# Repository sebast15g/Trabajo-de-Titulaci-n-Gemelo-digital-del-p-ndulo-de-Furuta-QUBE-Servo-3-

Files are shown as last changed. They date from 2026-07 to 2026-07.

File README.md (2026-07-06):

<h1 align="center">Gemelo digital del péndulo invertido de Furuta</h1>
<h3 align="center">Quanser QUBE-Servo 3 · modelo analítico · EKF · control · tiempo real</h3>

<p align="center">
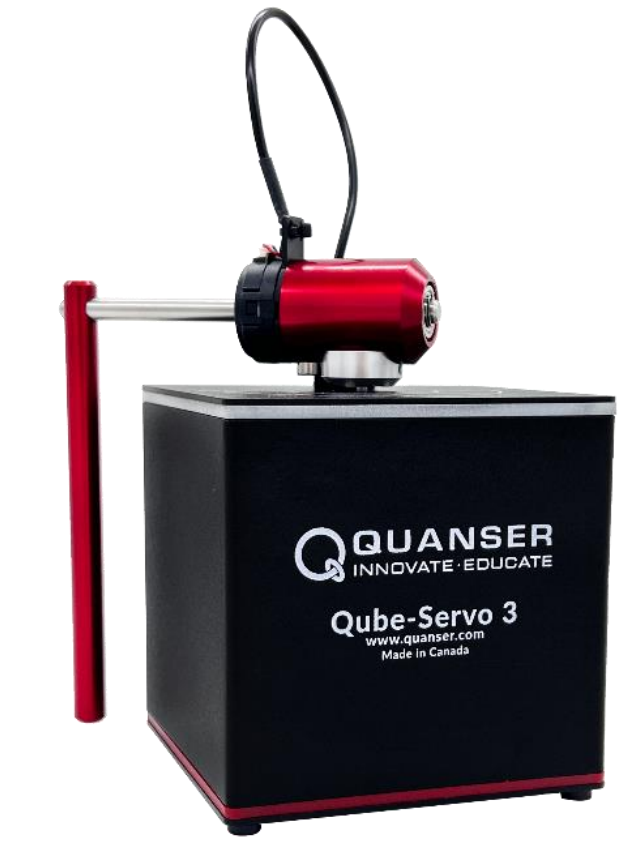
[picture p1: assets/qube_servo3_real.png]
Quanser QUBE-Servo 3 con el péndulo de Furuta
  
  &nbsp;&nbsp;&nbsp;
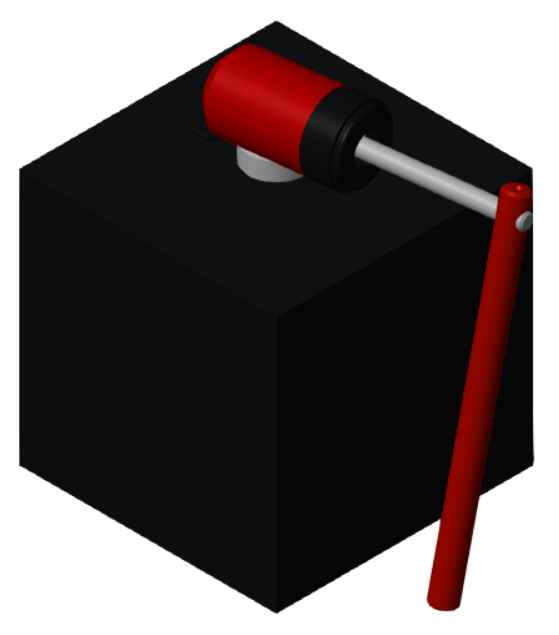
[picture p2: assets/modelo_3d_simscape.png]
Modelo 3D en Simscape Multibody
  
</p>
<p align="center"><em>Izquierda: el equipo real (planta M0). Derecha: el modelo 3D en Simscape Multibody (M2).</em></p>

<p align="center">
  
  
  
  
</p>

---

Este repositorio reúne el código, los datos, los modelos y las figuras del trabajo de
titulación *«Evaluación del impacto de la simulación en tiempo real en la fidelidad de un
gemelo digital aplicado al péndulo invertido QUBE-Servo 3»* (Universidad de Cuenca,
Facultad de Ingeniería, 2026).

El objetivo es construir un **gemelo digital** del péndulo de Furuta del equipo Quanser
QUBE-Servo 3, validarlo contra el equipo real y estudiar cómo influye la **simulación en
tiempo real** en su fidelidad, sincronización y desempeño.

## Idea en una figura

El trabajo maneja tres representaciones de la misma planta y las hace convivir:

| | Descripción |
|---|---|
| **M0 — real** | El equipo físico QUBE-Servo 3 (foto de la izquierda), leído por QUARC. |
| **M2 — 3D** | Modelo de alta fidelidad SolidWorks → Simscape Multibody (imagen de la derecha). |
| **M1 — analítico** | Modelo por Euler-Lagrange, `f(x,u)` y jacobianos en forma cerrada; es el gemelo que se despliega. |

Sobre M1 se cierra el lazo con un **observador (filtro de Kalman extendido, EKF, de estado
aumentado)** que estima el estado y la perturbación del cable a partir de los encoders, y
un **banco de control** (swing-up por energía + balance LQI/LQR/PD/PID). El mismo M1 se
ejecuta sin cambios sobre cuatro sustratos (SIM, QSM, QHW, RTB) para medir el efecto de la
simulación en tiempo real.

## Modelo principal: `DT_bidireccional_RT`

El modelo integrador de todo el trabajo es **`modelos/gemelo/DT_bidireccional_RT.slx`**. Es
el gemelo digital bidireccional: acopla la planta real (por HIL/QUARC) con la planta digital
(Simscape 3D), comparte el observador EKF y el banco de control, y sincroniza ambos lados.

<p align="center">
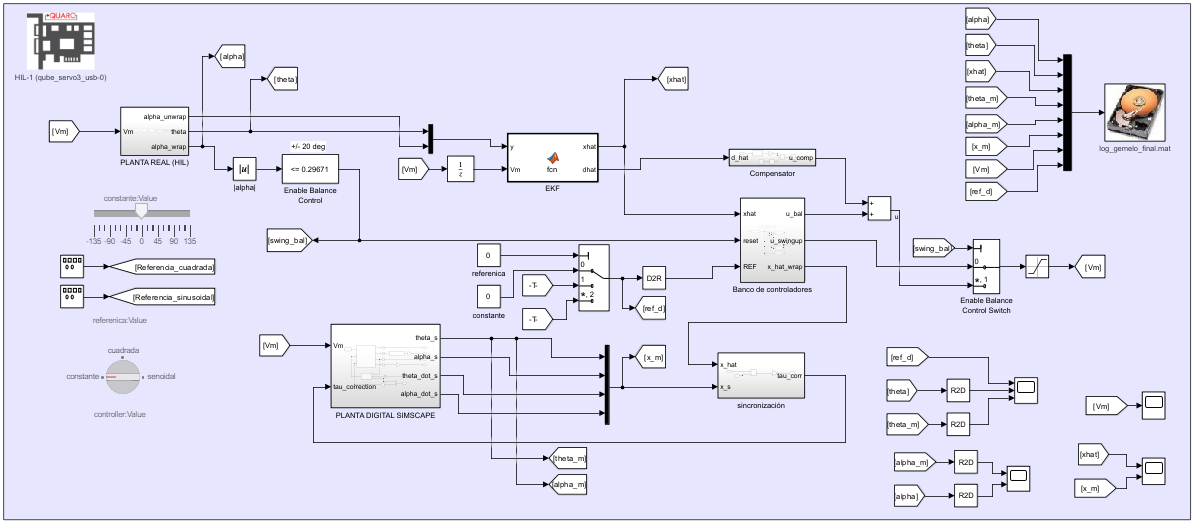
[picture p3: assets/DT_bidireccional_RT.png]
Modelo DT_bidireccional_RT en Simulink/QUARC
  
</p>

De un vistazo, en la captura: el bloque **PLANTA REAL (HIL)** (lectura de θ, α por QUARC), el
**EKF** que entrega `x̂` y la perturbación estimada `d̂`, el **banco de controladores** con la
conmutación swing-up → balance (`|α| ≤ 0.297 rad`), la **PLANTA DIGITAL SIMSCAPE** (el espejo
3D), el bloque de **sincronización** entre ambos, y el registro a `log_gemelo_final.mat`.

> Nota: `DT_bidireccional_RT` compila y corre; los ensayos de seguimiento en tiempo real
> cargan referencias grabadas por corrida (`ref_u`, `ref_xhat`) y la ganancia de sincronía
> `Ksync_tau`, propios de cada experimento.

Otros modelos de interés:

| Modelo | Rol |
|---|---|
| `modelos/gemelo/DT_bidireccional_RT.slx` | **Gemelo bidireccional (principal).** |
| `modelos/gemelo/Comparacion_real_modelo3d.slx` | Real y 3D en paralelo, sin sincronización (verificación de construcción). |
| `modelos/ekf_control/Digital_twin_ekf_E1…E5.slx` | Construcción incremental del EKF + control (etapas E1–E5). |
| `modelos/modelo_3d/Ensamblaje_..._v4.slx`, `Model3d_Furuta_Pendulum.slx` | Modelo 3D (SolidWorks → Simscape), base de la calibración. |
| `RTS_modalidades/` | El mismo M1 en las 4 modalidades de ejecución (SIM/QSM/QHW/RTB). |

## Estructura del repositorio

```
TESIS_FINALES/
├── codigo/            Scripts y funciones de MATLAB, por etapa
│   ├── parametros_furuta.m        Parámetros físicos finales (cargar primero)
│   ├── referencia/                Parámetros de referencia de Quanser
│   ├── identificacion/            Identificación por ensayo aislado 
│   ├── validacion/                Validación de fricción y retorno del cable
│   ├── modelo_control/            Modelo analítico M1, EKF y control 
│   └── gemelo/                    Real vs. 3D y gemelo bidireccional 
├── datos/             Datos de entrada y registros (.mat/.csv), por tema
├── figuras/           Figuras del Desarrollo y del Anexo, por tema
├── modelos/           Modelos de Simulink/Simscape (.slx), por tema
├── RTS_modalidades/   Las 4 modalidades (SIM/QSM/QHW/RTB) y su comparación
├── assets/            Imágenes de esta portada
├── setup_paths.m      Prepara el path y carga los parámetros
├── repo_root.m        Devuelve la raíz del repositorio
├── INDICE_documentacion.md   Índice unificado de la documentación
├── LICENSE            Licencia MIT
└── CITATION.cff       Cómo citar
```

Cada carpeta de nivel superior incluye su propio `README.md` con el detalle de su contenido.

## Requisitos

- MATLAB (probado en R2025a; compatible desde R2019a, versión de la `quarc_library` usada).
- Simulink, Simscape y Simscape Multibody.
- Symbolic Math Toolbox (derivación del modelo y de las funciones del EKF).
- Control System Toolbox (LQR/LQI) y Simulink Control Design (linealización del 3D).
- Statistics and Machine Learning Toolbox (algunos estimadores de la identificación).
- QUARC (Quanser) para las corridas en tiempo real y contra el hardware; no es necesario
  para la simulación offline ni para los scripts de post-proceso.

## Uso rápido

```matlab
% 1) Desde la raíz del repositorio, preparar el path y cargar los parámetros:
setup_paths        % añade codigo/ datos/ modelos/ RTS_modalidades/ al path
                   % y deja el struct 'p' en el workspace (parametros_furuta.m)

% 2) Abrir cualquier modelo desde su subcarpeta: su PreLoadFcn localiza la raíz,
%    arma el path y carga los parámetros automáticamente. Por ejemplo:
open_system('DT_bidireccional_RT')      % el modelo principal
open_system('Digital_twin_ekf_E1')      % una etapa del EKF

% 3) Correr los scripts de identificación / validación / comparación, p. ej.:
calc_friction               % identificación de la fricción del motor
comparar_analitico_simscape % modelo analítico M1 vs. modelo 3D M2
```

Los scripts resuelven sus datos por el path; no usan rutas absolutas. Los scripts de
post-proceso de las modalidades están en `RTS_modalidades/scripts/`.

## Parámetros físicos (valores finales adoptados)

| Grupo | Parámetro | Valor |
|---|---|---|
| Péndulo (α) | masa `mp`, longitud `Lp` | 0.024 kg, 0.12865 m |
| | Coulomb `Tc_alpha` | 6.1×10⁻⁶ N·m |
| Brazo (θ) | inercia `Jr` (eje motor) | 1.38×10⁻⁴ kg·m² |
| | viscoso `Dr` | 3.975×10⁻⁴ N·m·s/rad |
| Cable del encoder | rigidez `kc` | 2.384×10⁻³ N·m/rad |
| Motor DC | `Rm`, `kt = km` | 7.5 Ω, 0.0422 |
| Muestreo | `Ts` | 0.002 s (500 Hz) |
| Gravedad local | `g` | 9.7807 m/s² |

## Resultados principales

- El modelo analítico M1 reproduce al modelo 3D M2 con RMSE θ = 0.64°, α = 0.83°; polo
  inestable en +13.42 rad/s.
- EKF de estado aumentado sobre el equipo real: RMSE θ, α ≈ 0.03°.
- El sustrato de ejecución no cambia la fidelidad (RTB ≈ QSM ≈ SIM, mismo M1, todas dentro
  de la brecha M1↔M0); el delta entre modalidades mide la simulación en tiempo real (jitter,
  overruns, integrador). Detalle en `RTS_modalidades/`.

## Documentación

El punto de entrada único a toda la documentación es
[`INDICE_documentacion.md`](INDICE_documentacion.md). El estado global del trabajo está en
[`ESTADO_FINAL_PROYECTO.md`](ESTADO_FINAL_PROYECTO.md).

## Licencia y cómo citar

Código, datos y modelos se publican bajo licencia **MIT** (ver [`LICENSE`](LICENSE)). Si
utiliza este repositorio, por favor cite la tesis asociada (ver
[`CITATION.cff`](CITATION.cff)):

> Bermeo García, P. A.; Guazhima Fernández, S. S. (2026). *Evaluación del impacto de la
> simulación en tiempo real en la fidelidad de un gemelo digital aplicado al péndulo
> invertido QUBE-Servo 3*. Trabajo de titulación, Universidad de Cuenca, Facultad de
> Ingeniería.

## Autores

**Pablo Andrés Bermeo García** · **Sebastián Stalin Guazhima Fernández**
Universidad de Cuenca — Facultad de Ingeniería

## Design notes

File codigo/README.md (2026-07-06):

# codigo/

Scripts y funciones de MATLAB del gemelo digital, organizados por etapa. Antes de
ejecutar cualquier archivo, correr `setup_paths.m` en la raíz del repositorio: arma
el path y deja el struct de parámetros `p` en el workspace (`parametros_furuta.m`).

- `parametros_furuta.m` — parámetros físicos finales (archivo central; cargar primero).
- `Ensamblaje_..._v4_DataFile.m` — `smiData` (geometría/inercias/CoM del CAD).
- `referencia/` — parámetros de referencia del péndulo rotatorio de Quanser.
- `identificacion/` — identificación de parámetros por ensayo aislado (§4.3):
  `motor_friccion/`, `cable_theta/`, `contacto_topes/`, `alpha/`, `inercia_Jr/`,
  `calibracion_voltaje/`.
- `validacion/` — validación de la fricción del motor y del retorno libre del cable (§4.3).
- `modelo_control/` — modelo analítico M1, observador EKF y banco de control (§4.4–§4.6).
- `gemelo/` — comparación real vs. modelo 3D y demostración del gemelo bidireccional (§4.8).

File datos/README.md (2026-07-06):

# datos/

Datos de entrada y registros (`.mat`/`.csv`) que consumen los scripts, por tema. Se
resuelven por el path (`setup_paths.m`), sin rutas absolutas.

- `motor_friccion/`, `cable_theta/`, `contacto_topes/`, `alpha/`, `calibracion_voltaje/`
  — datos de identificación de parámetros (§4.3).
- `control/` — logs del banco de controladores (LQR/LQI/PD/PID).
- `gemelo/` — logs de sincronización y de verificación de construcción (real vs. 3D).
- `modelo_control/` — artefactos del modelo y del observador (`banco_controladores.mat`,
  `modelo_furuta_EKF.mat`).
- `validacion/` — salidas de simulación para las figuras de validación.

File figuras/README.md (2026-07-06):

# figuras/

Figuras del capítulo de Desarrollo y del Anexo, organizadas por tema: `modelo_3d/`,
`motor_friccion/`, `cable_theta/`, `contacto_topes/`, `alpha/`, `modelo_analitico/`,
`ekf/`, `control/`, `gemelo/`, `validacion/`. Los nombres de archivo coinciden con los
que cita el documento LaTeX de la tesis.

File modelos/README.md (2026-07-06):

# modelos/

Modelos de Simulink/Simscape (`.slx`) por tema: `modelo_3d/`, `motor_friccion/`,
`cable_theta/`, `contacto_topes/`, `alpha/`, `ekf_control/`, `gemelo/`, `validacion/`.

Cada modelo trae un `PreLoadFcn` que localiza la raíz del repositorio (buscador por
marcador), arma el path y carga los parámetros; no requiere preparación manual. Los
modelos 3D ejecutan además el `DataFile` para poblar `smiData` antes de compilar.

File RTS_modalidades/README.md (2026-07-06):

# RTS_modalidades — paquete de la etapa de modalidades (fidelidad + RTS)

Consolida el estudio de las **4 modalidades** del gemelo M1 del péndulo de Furuta contra la planta real
M0, en los 3 experimentos (E1 caída libre, E2 respuesta forzada, E3 lazo cerrado swing-up+balance+EKF).

## Estructura
- **`RTB/`** — RT Box (PLECS): figuras a 2 ms, overlays, barridos, métricas, esquemáticos PLECS, scopes PDF, sweeps CSV.
- **`QSM/`** — QUARC-modelo: esquemáticos, scopes, figuras del barrido (fast timer).
- **`QHW/`** — QUARC-real (M0): esquemáticos, scopes.
- **`SIM/`** — sim normal: métricas RTF.
- **`comparacion/`** — 13 figuras comparativas + `comparacion_4mod.mat`, `barridos_qsm.mat`, memo comparativo.
- **`scripts/`** — todos los `.m` del post-proceso.
- **`docs/`** — documentos por modalidad + maestras + hallazgos + memos.

## Documentos por modalidad (docs/)
- `doc_RTB.md` y `doc_QSM.md` — **extensos** (implementación, solver, hallazgos, RTS, resultados).
- `doc_QHW.md` y `doc_SIM.md` — breves (corridas directas, sin ajustes de por medio).
- `COMPARACION_4_modalidades.md` — tablas de fidelidad y RTS + lectura para la tesis.
- Transversal: `hallazgo_QUARC_timer_floor_RTS.md`, `memo_correccion_2ms_RTBOX.md`,
  `GUIA_ubicacion_resultados_rtbox.md`, maestras RTS y SIM/QUARC.

## Figuras comparativas (comparacion/)
- 4-way (las 4 modalidades): `comp_E1_alpha_4mod`, `comp_E2_alpha_theta_4mod`,
  `comp_E3_{alpha,theta,Vm,alphadot,NIS,E}_4mod`.
- Cada modalidad a solas vs el real (3 subplots): `comp_E1_alpha_vsreal`,
  `comp_E2_{alpha,theta}_vsreal`, `comp_E3_{alpha,theta}_vsreal`.
- Convención: en E3 la α es continua (sin envolver) y referenciada a balance=0; se refleja SOLO la
  modalidad cuyo swing-up viene del lado contrario al real (resultó ser RTB).

## Resultado en una línea
El sustrato **no** cambia la fidelidad: RTB≈QSM≈SIM (misma M1) y todas aproximan al real M0 dentro de la
brecha M1↔M0 (~5% en E1; QSM≈QHW casi exacto en E3). El delta entre modalidades mide la **RTS**: SIM es la
cota libre (RTF 12–35×); RTB es *compute-bound* y determinista (jitter sub-µs, pero corrió a RTF≈2); QSM es
*timer/jitter-bound* (piso 1 ms sin fast timer, jitter ~320 µs); QHW usa el timebase HIL (jitter ~36–70 µs).
La diferencia numérica entre RTB y QSM/SIM con el mismo modelo es el **integrador** (Euler 0.5 ms en la box
vs RK4/ode4 en QUARC).

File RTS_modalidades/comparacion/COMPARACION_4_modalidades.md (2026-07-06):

# Comparación de las 4 modalidades — fidelidad y RTS (E1/E2/E3)

Cierre del estudio: el mismo gemelo M1 ejecutado en cuatro sustratos contra la planta real M0.
Modalidades: **RTB** (RT Box/PLECS), **QSM** (QUARC-modelo), **SIM** (sim normal offline), **QHW**
(QUARC-real = M0). Post-proceso reproducible en `SIM_QUARC_RTS/postproceso_comparaciones/`
(`comparar_4mod.m`, `crosscheck_rtbox.m`, `procesar_barrido_rts.m`). Datos en `comparacion_4mod.mat` y
`barridos_qsm.mat`.

> Convención de figuras: en el swing-up (E3) se homogeneiza el signo de α por modalidad (se invierte si
> el último vaivén antes de la captura viene del lado contrario) para que las curvas calcen. Aplica al
> real o al modelo indistintamente.

## 1. Fidelidad (gemelo vs real M0)

Como RTB, QSM y SIM comparten la MISMA M1, coinciden entre sí; la brecha de fidelidad es M1↔M0 y es
aproximadamente constante entre sustratos (el sustrato no cambia la fidelidad).

**E1 — caída libre (α):**

| modalidad | f_n [Hz] | ζ | ratio f_n vs real |
|---|---|---|---|
| RTB | 1.761 | 0.0525 | 0.97 |
| QSM | 1.724 | 0.0568 | 0.95 |
| SIM | 1.724 | 0.0568 | 0.95 |
| **QHW (M0)** | **1.818** | **0.0390** | — |

RTB/QSM/SIM se agrupan (~1.72–1.76 Hz); el real va ~5 % más rápido (inercias/acoplamiento). RTB queda
levemente por encima de QSM por el integrador (Euler 0.5 ms vs RK4). Figura: `comp_E1_alpha_4mod.png`.

**E2 — respuesta forzada (rangos, misma excitación |Vm|≤1.5 V):**

| modalidad | θ [min,max]° | α [min,max]° |
|---|---|---|
| RTB | [−136.1, 136.0] | [113.4, 237.1] |
| QSM | [−135.8, 135.8] | [123.6, 225.1] |
| SIM | [−135.8, 135.8] | [123.6, 225.1] |
| **QHW (M0)** | [−136.1, 136.2] | [124.1, 234.1] |

θ topa en ±135° en las cuatro; α ~±60° del colgado. RTB oscila un poco más en la cuadrada (0–10 s) por
sensibilidad del tope rígido al integrador, pero acotado al mismo régimen. El seguimiento del brazo (θ) y
de las fases multiseno/chirp es excelente entre las cuatro. Figura: `comp_E2_alpha_theta_4mod.png`.

**E3 — lazo cerrado (swing-up + balance + EKF):**

| modalidad | t_catch [s] | balance % | α̂_std° | θ_std° | NIS |
|---|---|---|---|---|---|
| RTB | 2.72 | 93.8 | 0.51 | 0.66 | 1.10 |
| QSM | 3.13 | 79.1 | 1.11 | 3.10 | 1.50 |
| SIM | 3.13 | 79.1 | 1.11 | 3.10 | 1.50 |
| **QHW (M0)** | 2.65 | 82.3 | 1.12 | 3.14 | 1.52 |

**QSM ≈ QHW casi exacto** (α̂_std 1.11 vs 1.12°, θ_std 3.10 vs 3.14°, NIS 1.50 vs 1.52): el modelo
reproduce el balance real. SIM = QSM (mismo modelo, offline). RTB balancea algo más apretado (α̂_std
0.51°) por sustrato bare-metal. El swing-up es sensible al arranque → t_catch varía (2.65–3.13 s), pero
las cuatro capturan y balancean. Figura: `comp_E3_alpha_4mod.png`. NIS ~1–2 en las cuatro → EKF
consistente.

## 2. RTS (impacto del tiempo real)

El contraste es **libre (SIM) vs tiempo real estricto (QSM/QHW/RTB)** y, dentro del tiempo real, **cómo
topa cada sustrato**.

| modalidad | RTF | TET (punto op., 2 ms) | umbral de overrun | jitter @2 ms | naturaleza |
|---|---|---|---|---|---|
| **SIM** | ≫1 (E1 12.3, E2 35.4, E3 15.4) | n/a | n/a | n/a | libre, sin tiempo real |
| **RTB** | =1 (corrió a ~2× pared, ver nota) | 6.7 µs abierto / 16.8 µs cerrado | ~5 µs abierto / ~10 µs cerrado | sub-µs (hardware-locked) | *compute-bound*, bare-metal |
| **QSM** | =1 hasta ~5 µs (colapsa 1 µs) | ~7–8 µs med (máx 200–415 µs) | ~5 µs (con fast timer) | ~320 µs (software Windows) | *timer/jitter-bound* |
| **QHW (M0)** | =1 | ~8–10 µs med | — (planta física) | ~36–70 µs (timebase HIL) | planta real en tiempo real |

**Barrido de paso (QSM, fast timer):** RTF=1 desde 2 ms hasta 5 µs; colapso en 1 µs (abierto RTF 0.685,
56.7 % overruns; cerrado RTF 0.319, 100 %). TET_max crece de ~200 µs a 36 ms al forzar la tasa (stalls de
Windows). Sin fast timer, QUARC (win64) tiene **piso duro en 1 ms** (rechaza pasos menores: "unable to set
base rate"); el fast timer libera tasas sub-ms a costa de mucho CPU (recomendado en multinúcleo) —
experimental. Tablas en `barridos_qsm.mat`.

**Barrido de paso (RTB):** abierto TET_max ~6.7–7.8 µs, umbral overrun ~5 µs (5120 overruns @5 µs, carga
150 %); cerrado TET_max ~16–17 µs (el EKF ~triplica el TET), umbral ~10 µs (10240 overruns). Fuente
`rts_sweep_*.csv` + Application Log (`rt_E*_<paso>.txt`).

**Notas de RTS:**
- **RTB RTF≈2 (hallazgo aparte):** el modelo avanza 2 ms/muestra y el wall-clock ~1 ms → la box ejecutó a
  2× la velocidad de pared (no sostuvo 1:1). No afecta la fidelidad (dinámica en tiempo-modelo).
- **Contraste de sustratos:** RTB gana en **determinismo** (jitter sub-µs acotado por hardware); QUARC+fast
  timer gana en **throughput mediano** (TET ~µs, CPU potente) a costa de una cola de latencia no acotada
  (stalls de ms) y mucho CPU. El sustrato determinista a paso fino es el **hardware timebase** (RT Box, o
  la tarjeta HIL del QUBE en QHW). Corrección de la tesis: QUARC (win64) usa **timer de software** de
  Windows, no de hardware.

## 3. Lectura para la tesis

- **Fidelidad:** M1 es un gemelo válido, con brecha M1↔M0 de ~5 % en frecuencia (E1), ~±10° cerca del tope
  (E2, cable-jack/conector) y balance real ligeramente más disperso (E3, stiction/ruido). La brecha es del
  MODELO, no del sustrato: RTB≈QSM≈SIM. El lazo cerrado (E3) es la validación más relevante y QSM≈QHW.
- **RTS:** el delta entre modalidades mide el impacto del tiempo real. SIM es la cota libre; RTB y QHW son
  deterministas por hardware; QSM depende del timer de software (piso 1 ms sin fast timer, jitter alto).
- **Pendiente de redacción:** RMSE θ/α alineado por τ* (E2, misma excitación) para cuantificar la brecha
  punto-a-punto; y la sección de Desarrollo "Implementación de las modalidades" (4 modalidades, E1/E2/E3,
  montajes con las capturas `*_SIMULINK.png`/`*_PLECS.png` y scopes `*_scope_*`).

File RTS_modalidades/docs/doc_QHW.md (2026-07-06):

# Modalidad QHW — QUARC-real (planta física, = M0) · recopilación

Modalidad de **la planta real bajo control en tiempo real**: el QUBE-Servo 3 físico conectado al kernel
QUARC por la **HIL API** de Quanser (`HIL Initialize`, `HIL Read Encoder`, `HIL Write Analog`). Es la
**referencia M0** contra la que se mide la fidelidad de las otras tres. Corridas simples, sin barrido ni
ajustes especiales: la planta física siempre corre en tiempo real. Datos en
`SIM_QUARC_RTS/{E1_QHW,E2_QHW,E3_QHW}`.

## 1. Montaje

Mismo esquema de Simulink/QUARC que QSM, pero la planta simulada se reemplaza por el I/O físico (HIL): el
encoder entrega θ y α, y el analógico escribe Vm al motor. Esquemáticos en `E*_QHW_SIMULINK.png`; scopes
de ángulos en `E*_scope_*.png` / `*_scope_theta_alpha.png`. En E3 el retardo del lazo lo introduce el
propio I/O físico (no hace falta el `Unit Delay z⁻¹` de QSM/SIM). **Signo del actuador: aquí SÍ va el `−1`
de `For +ve CCW`** (convención del hardware Quanser).

## 2. Consideraciones (pocas, por ser corridas directas)

- **E1 (caída libre):** el péndulo se **levanta a mano** hasta cerca del invertido y se suelta; el log trae
  un preámbulo de sujeción que hay que **recortar** (desde la soltada) antes de estimar `f_n`/ζ. Lo hace
  `ver_E1_qhw.m` / los overlays (detección del fin del "hold" y del primer cruce del colgado).
- **Convención de α:** el encoder da α con reposo (colgado) ≈ 180°; la comparación con el modelo usa
  `α_real ↔ π − α_modelo` cuando aplica (verificado: en E1 la convención salió **directa**, sin inversión).
- **No hay estado "verdadero"** aparte del encoder: `theta/alpha` = `theta_meas/alpha_meas`; las velocidades
  se toman del EKF o se derivan en post.

## 3. RTS

- **RTF = 1** por construcción (planta física en tiempo real). No hay barrido de paso (la planta no se
  puede acelerar/ralentizar).
- **TET** medio ~8–10 µs (bloque `Computation Time`). **Jitter ~36–70 µs**: la **tarjeta HIL del QUBE
  aporta un *hardware timebase*** que disciplina el muestreo del lazo — por eso QHW tiene mucho menos
  jitter que QSM (~320 µs, solo timer de software), aunque compartan el mismo kernel QUARC. Coincide con la
  recomendación de Quanser de usar un hardware timebase para Ts ≤ 2 ms.

## 4. Resultados (referencia de fidelidad M0)

- **E1:** f_n=1.818 Hz, ζ=0.0390.
- **E2:** θ ∈ [−136, 136]°, α ∈ [124.1, 234.1]°.
- **E3:** captura 2.65 s, balance 82.3%, α̂_std 1.12°, θ_std 3.14°, NIS 1.52. El balance real es
  reproducido casi exactamente por QSM.

## 5. Layout y scripts

QHW E1/E2 (6 filas): `[t, seq, t_model, θ, α, Vm]`. QHW E3 (14 filas): `[t, seq, θm, αm, Vm, θ̂, α̂, θ̇̂,
α̇̂, d̂, nis, mode, E, θref]` — **`mode` es la fila 12** (binaria) y la fila 13 es E (mJ); decodificado por
estadísticas para no confundir canales. Carga con `cargar_log_quarc.m`; verificación con `ver_E1_qhw.m` y
los overlays `overlay_qhw_rtb.m`.

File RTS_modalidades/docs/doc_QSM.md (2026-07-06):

# Modalidad QSM — QUARC-modelo (planta analítica M1 en el kernel de tiempo real) · recopilación completa

Modalidad de **simulación en tiempo real del gemelo M1 en el kernel QUARC** (target `quarc_win64`, sobre
Windows), sin hardware en el lazo. Junto con RTB, la más extensa por el trabajo de RTS y los hallazgos del
timer. Recopila montaje, solver, hallazgos del piso de 1 ms y el fast timer, barrido y resultados. Datos
en `SIM_QUARC_RTS/{E1_QSM,E2_QSM,E3_QSM}`; scripts/figuras en `TESIS_FINALES/RTS_modalidades/`.

## 1. Qué es y cómo se montó

El mismo M1 corre como bloques de Simulink compilados al kernel de tiempo real de QUARC en el PC. La
planta es **`furuta_planta_analitica.m`** (MATLAB Function): transcripción literal del C-Script `PLANTA`
de la RT Box (dinámica 2-DOF + tope θ=±135° + encoder), **verificada contra `furuta_f_aug` a 1.14e-13**.
El EKF es `ekf_step.m` (un paso del EKF aumentado, `nis` como reducción escalar para codegen). Swing-up de
Quanser + balance LQI. Esquemáticos en `E*_QSM_SIMULINK.png`; scopes de ángulos en `*_scope_*.png`.
Ruptura del lazo en E3 con `Unit Delay z⁻¹` (2 ms) para romper el lazo algebraico de la MATLAB Function
(feedthrough). Signo del actuador SIN el `−1` de `For +ve CCW` (ese `−1` es solo del hardware real, QHW).

## 2. Solver (clave de por qué difiere de la RT Box)

QSM/SIM integran M1 con **RK4 (`nsub=4` → subpaso 0.5 ms) = ode4**, dentro de la MATLAB Function; el
solver de Simulink/QUARC es **fixed-step ode4 (o discreto) a 2 ms**. La RT Box, en cambio, integra las
mismas ecuaciones con **Euler explícito** (su target no ofrece ode4 para el C-Script continuo). Misma
física y parámetros, distinto integrador → RK4 (QSM) es más preciso que Euler (RTB); la diferencia es
pequeña en E1 (1.72 vs 1.76 Hz) y visible bajo golpes al tope en E2. Es la razón numérica de que dos
modalidades con "el mismo modelo" no den bit-idénticas.

## 3. Hallazgo principal — piso de tasa base de 1 ms (win64) y fast system timer

Documentado en `hallazgo_QUARC_timer_floor_RTS.md`. Resumen:
- Por defecto, `quarc_win64` usa el **timer de software de Windows con resolución de 1 ms**. Solo admite
  pasos base múltiplos de 1 ms. **Por debajo de 1 ms el kernel rechaza el base rate** ("Unable to set base
  rate. A value is outside the valid range" / "Actual period will be 0"), tanto en Monitor & Tune como en
  standalone (descarta que sea límite de External Mode). Es un **límite entre QUARC y Windows**, no del
  cómputo (el TET sobra: ~7–8 µs). Quanser mismo llama "crude and inaccurate" a la tasa de 1 kHz de
  Windows.
- **Corrección importante de la tesis:** QUARC (win64) usa **timer de software**, NO "timer de hardware".
- **Checklist para ir más allá de 1 ms (experimental):** activar **"Allow use of fast system timer"**
  (Configuration Parameters → Code Generation → QUARC). Esto libera pasos sub-ms usando más recursos de los
  **núcleos de CPU** (muy intensivo en CPU; recomendado en sistemas con >2 núcleos; **siempre deshabilitado
  en 1 CPU**). Sin él, la corrida a <1 ms **da error de ejecución** (el piso descrito). Con él activado, el
  kernel acepta hasta 1 µs. Correr en **standalone** (`quarc_run` o doble-clic al `.rt-win64`), NO en
  Monitor & Tune (External Mode topa a 1 kHz por `quarc_comm`).
- **Caveat de logging a tasas rápidas:** el `seq` de 16 bits se desborda (a 1 µs, 15 M muestras) y corrompe
  el `t_model` reconstruido; usar el `t` del target y el `t_wall`, o loguear `seq` a 32 bits.

## 4. Captura de RTS y barrido de paso

Bloques QUARC: **`Computation Time`** (TET, opción *Output computation time of task*), **`System Time`**
(wall clock), **`Counter Free-Running`** (`seq`), dos `To File` (fid y rt=`[t,seq,t_model,t_wall,TET]`).
Post-proceso del barrido con **`procesar_barrido_rts.m`** (RTF, TET min/med/máx, overruns=#TET>paso, paso
real). El barrido es exclusivo de QSM (planta simulada): en QHW la planta es física y siempre corre en
tiempo real; en SIM no hay tiempo real.

**Barrido con fast timer (E1 abierto / E3 cerrado):**

| paso base | RTF abierto | RTF cerrado | TET med | TET máx | overruns |
|---|---|---|---|---|---|
| 2 ms → 500 µs | 1.000 | 1.000 | 7–10 µs | 200–600 µs | 0 |
| 100 µs | 1.000 | 1.000 | 4–5 µs | ~500 µs | 0.1 % |
| 10 µs | 1.000 | 1.000 | 2–3 µs | 0.8–2.6 ms | 1–2 % |
| 5 µs | 1.000 | 1.000 | 1.6–3 µs | 1.6–3.1 ms | 5–7 % |
| **1 µs** | **0.685** | **0.319** | ~1–2 µs | **13–36 ms** | 57–100 % |

Lectura: QSM **mantiene RTF=1 hasta ~5 µs** (con fast timer) y colapsa en 1 µs; alcanza esencialmente el
mismo paso fino que la RT Box (~5–10 µs), pero el **peor caso** (TET_max) crece a decenas de ms por los
stalls de scheduling de Windows, frente al jitter sub-µs de la box. Es *timer/jitter-bound* (con fast
timer) vs *compute-bound* (RT Box). Tablas en `barridos_qsm.mat`. Figuras
`E1_qsm_barrido_fasttimer.png`, `E3_qsm_barrido_abierto_vs_cerrado.png`.

**Jitter en el punto de operación (2 ms):** ~320 µs (solo timer de software de Windows, sin hardware
timebase) — mucho mayor que QHW (~36–70 µs, timebase HIL) y que la box (sub-µs). Para el punto de
operación conviene **desactivar el fast timer** (baja el TET_max y da el jitter representativo del sustrato
estándar).

## 5. Resultados

- **E1:** f_n=1.724 Hz, ζ=0.0568.
- **E2:** θ ±136°, α ∈ [123.6, 225.1]°.
- **E3:** captura 3.13 s, balance 79.1%, α̂_std 1.11°, θ_std 3.10°, NIS 1.50 → **≈ QHW casi exacto** (el
  modelo reproduce el balance real).

## 6. Scripts y archivos

`cargar_log_quarc.m` (carga robusta a MAT v4 mal finalizado), `procesar_barrido_rts.m`, `run_sim_normal.m`
(comparte con SIM), `furuta_planta_analitica.m`, `ekf_step.m`, `setup_swingup.m`. Doc del hallazgo:
`hallazgo_QUARC_timer_floor_RTS.md`. Maestra: `DOCUMENTACION_MAESTRA_SIM_QUARC_E1E2E3.md`.

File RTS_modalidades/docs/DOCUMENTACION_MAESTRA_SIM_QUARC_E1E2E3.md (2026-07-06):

# Documentación maestra — modalidades Simulink / MATLAB / QUARC (E1/E2/E3) y estudio de RTS

Documento de recopilación y procedimiento de la fase **Simulink/MATLAB/QUARC** del estudio de
fidelidad del gemelo digital del péndulo de Furuta (QUBE-Servo 3) y del impacto de la simulación
en tiempo real (RTS). Es la contraparte de `DOCUMENTACION_MAESTRA_RTS_E1E2E3.md` (RT Box) y cierra
las **tres modalidades que faltaban** para completar el estudio de cuatro sustratos. Redactado para
retomar el trabajo sin perder contexto y para alimentar los capítulos de Desarrollo y Resultados.

Estado: **completo** para E1, E2 y E3 en las tres modalidades (fidelidad + RTS + barridos donde
aplica). Falta solo el post-proceso comparativo final (fidelidad cruzada contra M0 + tablas
consolidadas), que es ya redacción de Resultados.

---

## 1. Objetivo y las tres modalidades de esta fase

El estudio compara **el mismo gemelo digital** ejecutado en cuatro sustratos contra la planta real
(M0). La RT Box quedó documentada aparte; esta fase añade las tres modalidades sobre Simulink/QUARC:

| ID | Nombre | Sustrato | Planta | RTF | Naturaleza |
|---|---|---|---|---|---|
| **SIM** | Sim normal | Simulink offline (PC) | modelo M1 (MATLAB Function) | ≫ 1 | libre, sin tiempo real |
| **QSM** | QUARC-modelo | kernel de tiempo real QUARC (PC) | modelo M1 | = 1 | tiempo real, planta simulada |
| **QHW** | QUARC-real | kernel QUARC (PC) + QUBE-Servo 3 físico | planta física M0 | = 1 | tiempo real, hardware (interfaz HIL) |

`RTB` (RT Box, PLECS Coder) es la cuarta modalidad. **M1** = modelo analítico de 4 estados
(`furuta_f_aug`, transcrito a `furuta_planta_analitica.m`); **M2** = modelo 3D Simscape, usado en su
momento para calibrar M1 (no interviene aquí como planta).

Dos familias de métricas, idénticas a la RT Box:
- **Fidelidad** (gemelo vs real): RMSE θ/α, error máximo, `f_n`/`ζ` (E1), índices de desempeño (E3),
  consistencia del EKF (NIS). Salen de las señales del modelo.
- **RTS** (impacto del tiempo real): RTF, TET, overruns, jitter, muestras perdidas. Salen del
  sustrato de ejecución.

**Aclaración de terminología (importante para la redacción).** En la taxonomía X-in-the-Loop, QSM y
RTB son **simulaciones en tiempo real** del gemelo (no HIL: no hay hardware en el lazo); QHW es la
**planta física bajo control en tiempo real** (M0). El término "HIL" se usa solo en el sentido
comercial de Quanser (la interfaz con el QUBE usa la HIL API: `HIL Initialize`, `HIL Read Encoder`,
`HIL Write Analog`), no en el de emulación de planta.

---

## 2. Convenciones comunes (no negociables — comunes con la RT Box §2)

1. **`Ts = 2 ms` (500 Hz)** como malla de muestreo/comparación en las cuatro modalidades.
2. **Solver Simulink/QUARC**: `ode4` (o discreto) a paso fijo `2e-3`. La planta M1 integra internamente
   por RK4 con `nsub = 4` subpasos (`h = 5e-4`, = paso base de la RT Box).
3. **Convención de ángulos**: θ y α en la del control, **α = 0 arriba, α = π colgado**. El encoder
   real entrega α; la comparación con el modelo usa `α_real ↔ π − α_modelo` en post-proceso.
4. **α SIEMPRE unwrapped hacia el EKF/control.** El encoder del QUBE es incremental (cuenta continua);
   la planta M1 entrega `alpha_meas` **cuantizada pero SIN envolver**, para que `nu = y − ŷ` del EKF no
   tenga saltos de 2π durante el swing-up. (En el log de fidelidad puede guardarse envuelta si se
   prefiere; el control usa la unwrapped.)
5. **Excitación E2** = `excitacion_Vm_e2` (33 s, 16500 muestras a 2 ms, |Vm| ≤ 1.5 V), desde
   `From Workspace` con *Interpolate data = OFF (ZOH)*, *Hold final value* — idéntica a la de la box.
6. **Condición inicial**: E1 `AL0 = 0.05` (cae desde arriba), E2 `AL0 = π`, E3 `AL0 = π` (colgado).
7. **El tiempo va como canal explícito** (fila 1 del log). En QUARC el `To File` antepone su tiempo
   automáticamente (a diferencia de PLECS); se reconstruye igual y `cargar_log_quarc.m` lo lee directo.
8. **Signo del actuador**: en SIM/QSM se usa `u = −Ka·[x̂;xᵢ]` sin el `−1` de `For +ve CCW`; ese `−1`
   solo aparece en QHW (hardware Quanser real).

---

## 3. La planta y el controlador (bloques Simulink reutilizados)

- **Planta M1 — `furuta_planta_analitica.m`** (bloque MATLAB Function): integrador discreto
  autocontenido (RK4, `nsub=4`) que es la **transcripción literal del C-Script `PLANTA` de la RT Box**.
  Incluye la dinámica Lagrangiana 2-DOF, el **tope mecánico θ = ±135°** (penalización unilateral
  resorte-amortiguador) y la **emulación del encoder** (cuantización 2π/2048, α unwrapped). Salidas:
  `theta, alpha, dtheta, dalpha, theta_meas, alpha_meas`. **Verificada contra `furuta_f_aug.m` a
  1.14e-13** (params actuales, `g = 9.7807`). No usa `furuta_f_param.m`, que quedó con `g = 9.77`
  horneada (desactualizada; regenerable con `derivar_furuta_f_param.m`).
- **EKF — `ekf_step.m`** (bloque MATLAB Function): un paso del EKF de estado aumentado (5 estados,
  predicción con Jacobiano + corrección + NIS). Entradas `y = [theta_meas; alpha_meas]` (unwrapped),
  `Vm`. Salidas `xhat = [θ̂,α̂,θ̇̂,α̇̂]`, `dhat`, `nis`. `nis` se calcula como reducción escalar
  `sum(nu.*(Sk\nu))` (garantiza `1×1` para codegen). Requiere `furuta_f_aug/_Fc/_meas/_Hjac` en el path.
- **Swing-up + balance**: swing-up de energía de Quanser (`ke=50`, `Er=2·mp·g·lp≈30.2 mJ`, `u_max=6`)
  con conmutación a balance (`catch` ~17–20°). Balance = **LQI del proyecto**
  `K_LQI = [-3.7921 -33.888 -1.4796 -2.9148 -4.4721]` (4 estados + integrador), NO la ganancia por
  defecto de Quanser. Energía `E = 0.5·Jp_cm·α̇² + mp·g·lp·(1+cos α)`, con α̂/α̇̂ del EKF.
- **Ruptura del lazo**: en E3 el lazo `planta → EKF → control → Vm → planta` se cierra con un
  **`Unit Delay z⁻¹`** (2 ms, inicial 0) entre el `Vm` del control y el `Vm` de la planta. En QSM/SIM es
  imprescindible (la planta MATLAB Function es feedthrough → sin el delay hay lazo algebraico). En QHW
  no hace falta: el hardware (HIL Read/Write) introduce el retardo de forma natural.

---

## 4. Logging (mismo vector de fidelidad que la RT Box §5)

Dos `.mat` por corrida unidos por `seq`, con el **tiempo como canal explícito** (fila 1).

- **Fidelidad `fid_E*_<mod>.mat`**:
  - E1/E2 (lazo abierto): `[t, seq, theta, alpha, dtheta, dalpha, theta_meas, alpha_meas, Vm]` (9 filas).
  - E3 (lazo cerrado): `+ [theta_hat, alpha_hat, dtheta_hat, dalpha_hat, dhat, nis, mode, E]`
    (y `theta_ref`) — hasta 18 filas.
  - En **QHW no hay estado "verdadero"** aparte del encoder: `theta/alpha` = `theta_meas/alpha_meas`;
    las velocidades se derivan en post o se toman del EKF.
- **Tiempo real `rt_E*_<mod>.mat`**:
  - **SIM**: solo `RTF` (struct escueto; TET/overruns/jitter = n/a).
  - **QSM/QHW**: `[t, seq, t_model, t_wall, TET]`, con `t_wall` del bloque QUARC **System Time** y `TET`
    del bloque **Computation Time** (opción *Output computation time of task*, modo *Wall clock*).

**Bloques de captura de RTS (QUARC):** `Counter Free-Running` (seq, sample time 0.002),
`System Time` (t_wall, *Wall clock*), `Computation Time` (TET, *Output computation time of task*),
dos `To File` (fid y rt). En SIM esos bloques QUARC son n/a; se desconectan y el RTF sale de
`tic/toc` alrededor de `sim()` (`run_sim_normal.m`).

---

## 5. Hallazgo principal de RTS — piso de tasa base de QUARC (win64)

Documentado en detalle en `hallazgo_QUARC_timer_floor_RTS.md` (en `E1_QSM/`). Resumen:

- Por defecto, el target `quarc_win64` usa el **timer de Windows con resolución de 1 ms**: solo admite
  pasos base múltiplos de 1 ms. **Por debajo de 1 ms el kernel rechaza el base rate** ("Unable to set
  base rate. A value is outside the valid range" / "Actual period will be 0"), tanto en External Mode
  como en standalone. Quanser mismo califica la tasa de 1 kHz de Windows de "crude and inaccurate" [1].
- La casilla **"Allow use of fast system timer"** (Config Params → QUARC) elimina ese piso y permite
  pasos sub-ms, a costa de mucho CPU (recomendado en multinúcleo) [1].
- **Distinción clave (timer-bound vs compute-bound):** la RT Box es *compute-bound* (timer de hardware
  fino; overrunea cuando el TET supera al paso, ~5–10 µs abierto, ~16–17 µs cerrado). QUARC por defecto
  es *timer-bound* (el cómputo sobra —TET ~7–8 µs— pero el reloj del SO topa en 1 ms). Con fast timer,
  QUARC pasa a *compute/jitter-bound* y mantiene RTF=1 hasta ~5 µs (E1 y E3), colapsando en 1 µs
  (RTF 0.68 abierto, 0.32 cerrado; TET_max hasta 36 ms por stalls de Windows).
- **Trade-off del sustrato:** QUARC (PC potente + fast timer) gana en **throughput mediano** (TET ~µs,
  menor que la box); la RT Box gana en **determinismo** (jitter sub-µs acotado por hardware vs stalls de
  ms de Windows). En QUARC el costo del EKF (lazo cerrado) es despreciable porque el PC es rápido; en la
  box es visible (por eso su umbral cerrado 16 µs ≫ abierto 5–10 µs).
- **Jitter según timebase** (a 2 ms, sin overruns): RT Box sub-µs ≪ QHW ~36–70 µs (timebase HW de la
  tarjeta HIL disciplina el lazo) ≪ QSM ~320 µs (solo timer de software Windows, sin hardware timebase).

Referencia: [1] Quanser Inc., "Configuration Parameters," QUARC Documentation,
https://docs.quanser.com/quarc/documentation/configuration_parameters.html

---

## 6. Metodología del barrido de paso (solo QSM)

El barrido de paso base (headroom de tiempo real) es **exclusivo de QSM** (planta simulada): en QHW la
planta es física y corre en tiempo real pase lo que pase; en SIM no hay tiempo real. Procedimiento:

1. Todos los bloques con sample time a **`-1` (inherit)**; controlar la tasa solo con el *Fixed-step
   size = `Ts_base`* del solver → modelo mono-tasa (evita el error "Data integrity issue" de multi-tasa).
2. Barrer `Ts_base`: por defecto solo 2e-3 y 1e-3 (piso del timer); **con fast timer** 5e-4, 2.5e-4, 1e-4,
   5e-5, 1e-5, 5e-6, 1e-6 hasta el colapso de RTF.
3. Correr en **standalone** (`quarc_run` o doble-clic al `.rt-win64`), no en Monitor & Tune (External
   Mode topa a 1 kHz por `quarc_comm`, aparte del kernel). Leer el `rt_*.mat` (Computation Time) o la
   consola de QUARC.
4. Un barrido por **tipo de lazo**: abierto (E1, cubre E2) y cerrado (E3). Post-proceso con
   `procesar_barrido_rts.m` (RTF, TET min/med/max, overruns, paso real vs paso nominal).
5. Fidelidad se toma aparte, en el punto de operación (2 ms).

Caveat de logging a tasas rápidas: el contador `seq` de 16 bits se desborda (a 1 µs, 15 M muestras) y
corrompe el `t_model` reconstruido; usar el `t` del target (fila 1) y el `t_wall`, o loguear `seq` a 32
bits. Para las corridas de punto de operación (2 ms), **desactivar el fast timer** (baja el TET_max y da
el jitter representativo del sustrato normal).

---

## 7. Resultados preliminares (RTS)

**Sim normal (offline, RTF ≫ 1):** E1 RTF 12.3, E2 RTF 35.4, E3 RTF 15.4 (tiempo de pared ~1 s en los
tres; el RTF incluye el overhead fijo de init de Simulink → es un límite inferior conservador). TET/
overruns/jitter = n/a.

**QSM — punto de operación (2 ms):** RTF=1, 0 overruns, 0 muestras perdidas. TET medio ~8–10 µs (abierto)
y ~15 µs (cerrado, con EKF); jitter ~320 µs (software puro, sin hardware timebase).

**QSM — barrido de paso (fast timer):** RTF=1 hasta ~5 µs; colapso en 1 µs. Ver
`E1_qsm_barrido_fasttimer.png` (abierto) y `E3_qsm_barrido_abierto_vs_cerrado.png` (comparativa).

**QHW — punto de operación (2 ms):** RTF=1, 0 overruns, jitter ~36–70 µs (timebase HW de la tarjeta HIL).
Es la referencia M0.

---

## 8. Consideraciones de fidelidad — por qué difieren real (M0) y modelo (M1)

(Se ahondará en la redacción; aquí el resumen de las causas físicas identificadas.)

- **Frecuencia de α (E1, caída libre):** el modelo va ~8–9 % más lento que el real (2.20 vs 2.40 Hz). Es
  dominado por las **inercias** (Jr del brazo, Jp del péndulo) y el acoplamiento con el brazo libre; el
  cable contribuye de forma secundaria. Los parámetros son de CAD (SolidWorks + calibrador), físicamente
  fundamentados; **no se sobreajustan** para no degradar el modelo en el resto del régimen.
- **Cable-jack (E2, cerca del tope):** el conector del encoder se enrosca a la base del QUBE; al girar el
  brazo al tope (±135°) el jack rota y el cable se enrolla, con rigidez dependiente de la posición,
  histéresis y reposo θ₀ que se desplaza. El error de θ crece hacia el tope (14°→18°) y deja un offset
  residual (~14°) que se acumula. **No representable con parámetros constantes** — M1 modela el cable
  como resorte lineal + viscoso. Es una limitación del régimen, no un mis-tuning.
- **Conector USB-C (E2):** el conector físico de alimentación/USB-C obstruye al péndulo cuando |Vm|≥1 V
  lo lanza al tope; le quita amplitud y cambia el rebote. Es un **artefacto del banco de pruebas**, no un
  déficit del modelo — argumento en contra de tocar parámetros.
- **Stiction y ruido (E3, balance):** el real oscila **4× más en θ** que el modelo (std 2.75° vs 0.69°),
  porque el gemelo limpio no tiene cable-jack, stiction, ruido de encoder ni jitter que rechazar. La
  subactuación obliga a mover θ para sostener α; a más perturbación real, más movimiento de θ. Es una
  medida directa de la brecha de fidelidad en lazo cerrado, no un fallo del control.

Conclusión metodológica: M1 es un **gemelo válido para su propósito** (estimación + control + estudio de
RTS), con un **régimen de validez documentado** (excelente a baja frecuencia/amplitud moderada; se
degrada cerca del tope, en alta frecuencia y con el conector). El lazo cerrado (E3) coincide muy bien
real vs modelo (mismo control, tiempos y amplitudes de swing-up), que es la validación más relevante para
un gemelo destinado a control. Como M1 es idéntico en las cuatro modalidades, esta brecha **se cancela**
en el delta entre modalidades → no afecta al estudio de RTS.

---

## 9. Inventario de la carpeta `SIM_QUARC_RTS/`

Estructura por modalidad (paralela a `RTS_SIM_RTBOX1/`). Cada subcarpeta trae el `.slx` del modelo, el
`.rt-win64` compilado (QUARC), los `.mat` de fidelidad y RT, capturas del modelo Simulink y de los
scopes θ/α, y algún `.txt` de consola (se conservan a modo de evidencia; se descartan para el análisis,
que sale de los `.mat`).

- **`E1E2E3_sim_normal/`**: `E1_SIM.slx`, `E2_SIM.slx`, `E3_SIM.slx`; `fid_E{1,2,3}_sim.mat`,
  `rt_E{1,2,3}_sim.mat` (solo RTF); `run_sim_normal.m` (corre offline y mide RTF por `tic/toc`).
- **`E1_QSM/`**: `E1_QSM.slx` + `.rt-win64`; `fid_E1_qsm.mat`; `rt_E1_qsm.mat` (2 ms) y el **barrido**
  `rt_E1_qsm_{2e_3,1e_3,5e_4,1e_4,5e_5,1e_5,5e_6,1e_6}.mat`; capturas `E1_QSM_SIMULINK.png`,
  `E1_qsm_scope_theta_alpha.png`; `.txt` de consola; y **`hallazgo_QUARC_timer_floor_RTS.md`**.
- **`E2_QSM/`**: `E2_QSM.slx` + `.rt-win64`; `fid_E2_qsm.mat`, `rt_E2_qsm.mat` (2 ms); capturas.
- **`E3_QSM/`**: `E3_QSM.slx` + `.rt-win64`; `fid_E3_qsm.mat`; barrido cerrado
  `rt_E3_qsm_{2e_3…1e_6}.mat`; capturas.
- **`E1_QHW/`, `E2_QHW/`, `E3_HQW/`** (planta real, M0): `.slx` + `.rt-win64`; `fid_E*_qhw.mat`,
  `rt_E*_qhw.mat` (solo punto de operación 2 ms, sin barrido — planta física); capturas del modelo y de
  los scopes; `.txt` de consola.
- **`postproceso_comparaciones/`**: `ver_E1_qhw.m` (verificador E1: layout, signo de α, `f_n`/`ζ`,
  jitter/RTF/TET), `E1_overlay_preview.m`, `E2_overlay_preview.m` (overlays real vs analítico con
  detección de inversión de signo), `procesar_barrido_rts.m` (tabla RTS del barrido).

Nombres: `fid_*` = fidelidad, `rt_*` = tiempo real; el sufijo en `rt_E*_qsm_<paso>` = paso base del
barrido. `*_SIMULINK.png` = bloques y conexiones del modelo; `*_scope_*` = scopes θ/α.

> Nota: la subcarpeta de la planta real de E3 está nombrada `E3_HQW` (typo de `E3_QHW`); el contenido es
> el correcto de QHW-E3.

---

## 10. Post-proceso y estado / checklist

- **Carga**: `cargar_log_quarc.m` lee cualquier `.mat` de SIM/QSM/QHW (orienta a señales×N, recorta
  padding, espera el tiempo en la fila 1). `cargar_log_rtbox.m` para la box.
- **Fidelidad**: alinear por correlación cruzada `τ*`, aplicar `α_real ↔ π−α_modelo`, decimar a 2 ms, y
  emitir RMSE θ/α, e_max, `f_n`/`ζ` (E1), índices E3, NIS. `validar_resultados.m` cubre estimación/balance.
- **RTS**: RTF (SIM ≫1; resto =1), jitter/TET/overruns (QUARC, box), barridos (`procesar_barrido_rts.m`).

Checklist:
- [x] SIM — E1/E2/E3 offline + RTF.
- [x] QSM — E1/E2/E3 fidelidad a 2 ms + barridos abierto (E1) y cerrado (E3) + hallazgo del timer floor.
- [x] QHW — E1/E2/E3 fidelidad a 2 ms (M0) + RTS.
- [ ] Post-proceso comparativo final (fidelidad cruzada vs M0 + tablas RTS de las 4 modalidades).
- [ ] Redacción de Desarrollo (esta carpeta, capturas de modelos y scopes) y Resultados (tablas).

---

## Referencia
[1] Quanser Inc., "Configuration Parameters," QUARC Documentation.
    https://docs.quanser.com/quarc/documentation/configuration_parameters.html
    (parámetros *Allow use of fast system timer* y *Stop the model if an overrun occurs*).

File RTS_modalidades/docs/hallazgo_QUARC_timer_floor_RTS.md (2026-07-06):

# Hallazgo — piso de tasa base de QUARC (win64) en el estudio de RTS

Nota técnica para la redacción del capítulo de RTS. Documenta por qué el sustrato QUARC
(QSM y QHW, target `quarc_win64`) no admite pasos de muestreo por debajo de ~1 ms con la
configuración por defecto, cuál es la causa, la opción para superarlo, y qué significa para
la comparación con la RT Box.

## 1. Observación

Al barrer el paso base del modelo E1-QSM (planta analítica en el kernel de tiempo real de
QUARC), las corridas fallan **a partir de 5e-4 s (2 kHz)**, tanto en Monitor & Tune (External
Mode) como en ejecución **standalone** (doble clic al `.rt-win64`, sin host). Standalone (que
descarta cualquier límite de External Mode) imprime:

```
Creating main thread with priority 2 and period 0.0005...
*** Actual period will be 0 ***
Unable to set base rate. A value is outside the valid range.
---- Model 'E1_QSM' terminated (exit code 1) ----
```

Mientras que a 2e-3 y 1e-3 corre normal:

```
Creating main thread with priority 2 and period 0.002...
Main thread exited
---- Model 'E1_QSM' terminated (exit code 0) ----
```

El mensaje **"Actual period will be 0"** es el diagnóstico: el período solicitado (500 µs),
convertido a las unidades del timer del sistema, redondea a 0 → período inválido → el kernel
rechaza. Como aparece también en standalone, **es un límite del kernel de tiempo real, no de
la comunicación External Mode.**

## 2. Causa raíz: resolución del timer del sistema (Windows)

Por defecto, el target `quarc_win64` usa el **timer del sistema de Windows, con resolución de
1 ms**. Los períodos válidos son múltiplos enteros de ese tick: 2 ms y 1 ms funcionan; 0.5 ms
no se puede representar (0.5 ticks → 0). Documentación de Quanser (Configuration Parameters,
parámetro *Stop the model if an overrun occurs*):

> "the Windows target sampling rate of 1 kHz is crude and inaccurate in some systems and
> causes a lot of overrun occurrences in your model."

Es decir, el propio fabricante califica de "tosca e inexacta" la tasa de 1 kHz del target de
Windows; por eso el corte por overrun viene desactivado de fábrica.

## 3. Opción para superarlo: *fast system timer*

QUARC ofrece en *Configuration Parameters → Code Generation → QUARC* la casilla
**"Allow use of fast system timer"** (desactivada por defecto). De la documentación:

> "It is used for sample times faster than one or two milliseconds ... allows sample times
> faster than one millisecond to be specified. ... If this option is not checked then sample
> times are limited to one millisecond."

Restricciones documentadas del fast system timer:
- Es **muy intensivo en CPU**; conviene en sistemas con **más de 2 núcleos**.
- Está **siempre deshabilitado en sistemas de 1 CPU** (la casilla se ignora).
- Para tasas rápidas y deterministas, Quanser recomienda usar un **hardware timebase** (el
  timer de una tarjeta HIL) en lugar del timer de software.

Consecuencia: para empujar el barrido de QSM por debajo de 1 ms hay que **activar el fast
system timer**. Sin él, los únicos pasos factibles son 2 ms y 1 ms.

## 4. Interpretación para la tesis: timer-bound vs compute-bound

El resultado central es que **los dos sustratos topan con el tiempo real por razones
distintas**:

- **RT Box (PLECS Coder, bare-metal):** *compute-bound*. Tiene un timer de hardware de
  resolución fina (permite fijar pasos hasta 5 µs), así que corre hasta que el **cómputo** ya
  no alcanza: overrunea cuando el TET (~6–7 µs en lazo abierto) supera al paso, alrededor de
  5–10 µs.
- **QUARC win64 (sobre Windows):** *timer-bound*. El cómputo sobra por amplio margen (TET
  ~7–8 µs, ver §5), pero el **reloj del sistema operativo (1 ms)** es el techo: el kernel
  **rechaza** (bounds check del período) cualquier paso < 1 ms mucho antes de que el cómputo
  sea un problema. Rechaza en vez de overrunear.

Esta distinción es más informativa que un simple "QUARC es más lento": el cuello de botella
del sustrato QUARC por defecto no es la potencia de cálculo sino la **granularidad del reloj
del SO**. Con el fast system timer activado, QUARC podría bajar de 1 ms y eventualmente
llegar también a un límite de cómputo (como la box), a costa de mucho uso de CPU.

## 5. Datos medidos (E1-QSM, lazo abierto, corridas válidas)

| paso base | dt log | TET min | TET medio | TET máx | carga (TET/Ts) | overruns |
|---|---|---|---|---|---|---|
| 2 ms  | 2004 µs | 1.7 µs | 8.4 µs | 414.7 µs | 0.4 % | 0 |
| 1 ms  | 1001 µs | 1.0 µs | 7.1 µs | 201.9 µs | 0.7 % | 0 |
| ≤ 0.5 ms | — | — | — | — | — | **no arranca** ("unable to set base rate") |

El TET mediano (~7–8 µs) es casi constante y del mismo orden que el de la RT Box (6–7 µs); la
diferencia está en el **máximo** (200–415 µs), que son los picos de jitter de scheduling de
Windows (tiempo real blando), muy por encima del jitter sub-µs de la box (hardware-locked).

## 6. Implicación metodológica y próximos pasos

- Reportar el piso de QUARC como **hallazgo del sustrato**, no como fallo: QUARC (win64, timer
  por defecto) sostiene hasta 1 kHz; por debajo rechaza el base rate por resolución del reloj.
- Para un barrido de QUARC comparable en rango al de la box, **activar "Allow use of fast
  system timer"** y repetir 5e-4, 2.5e-4, 1e-4, ... hasta el nuevo límite (que ya sí debería
  ser de cómputo/jitter). Documentar que se requirió el fast timer y sus caveats.
- El barrido de la box y el de QUARC no son directamente superponibles en el eje del paso: la
  box mide *headroom de cómputo*; QUARC (por defecto) mide *resolución de reloj*. La tabla
  comparativa debe dejar esto explícito.
- El sustrato realmente determinista a paso fino es el **hardware timebase** (RT Box, o la
  tarjeta HIL del QUBE en QHW), no el timer de software de Windows.

## Referencia
[1] Quanser Inc., "Configuration Parameters," QUARC Documentation.
    https://docs.quanser.com/quarc/documentation/configuration_parameters.html
    (parámetros *Allow use of fast system timer* y *Stop the model if an overrun occurs*).

---

## 7. Resultado con el *fast system timer* ACTIVADO (standalone)

Al activar "Allow use of fast system timer" y correr en standalone, QUARC **acepta** tasas
base hasta 1 µs (ya no aparece "unable to set base rate"): la consola imprime períodos de
1e-4, 1e-5 y 1e-6 con "Main thread exited" y exit code 0. El piso de 1 ms del timer por
defecto queda eliminado.

Pero *aceptar* la tasa no es *cumplir* el tiempo real. Medido en el `rt` de la corrida a
**1 µs** (paso nominal 1e-6 s):

| magnitud | valor |
|---|---|
| RTF (modelo/pared) | **0.685** (15.00 s de modelo en 21.91 s de pared) → NO alcanza |
| paso real logrado | 1.46 µs (pedido 1.00 µs) |
| muestras con TET > paso | 57 % |
| TET mediana | ~1.0 µs |
| TET máximo | **36.5 ms** (stall de scheduling) |

Interpretación: con el fast timer, QUARC pasa de *timer-bound* a **compute/jitter-bound**
—el mismo régimen que la RT Box—. A escala de µs ya no mantiene RTF=1.

**Matiz importante (trade-off del sustrato):**
- La **mediana** de QUARC es excelente (TET ~1 µs), de hecho **menor que la de la RT Box**
  (~6–7 µs), porque el CPU del PC de escritorio es mucho más potente que el procesador
  embebido de la box. En throughput típico, QUARC puede pisar más fino.
- El **peor caso** es catastrófico: stalls de decenas de ms (36.5 ms medido), producto del
  no-determinismo de Windows. La RT Box tiene jitter sub-µs acotado por hardware.

Conclusión: no es que un sustrato sea "mejor". QUARC (fast timer) gana en **throughput
mediano** (CPU potente), la RT Box gana en **determinismo** (jitter acotado). El fast timer
desbloquea tasas finas a costa de mucho CPU y de una cola de latencia no acotada.

El cruce RTF=1 (headroom real de QUARC con fast timer) está entre 1e-3 (RTF≈1, §5) y 1e-6
(RTF=0.685); para fijarlo hay que medir los puntos intermedios (1e-5, 1e-4, 5e-6, 2e-6).

Caveat de logging a tasas rápidas: el contador `seq` de 16 bits **se desborda** (a 1 µs da
15 M muestras), lo que corrompe el `t_model` reconstruido (aparece topado en 131 s =
65536·2 ms). Para estas corridas hay que usar el `t` del target (fila 1) y el `t_wall`
(System Time), o loguear `seq` a 32 bits.

### 7.1 Barrido completo con fast timer (E1-QSM, lazo abierto)

| paso base | RTF | TET med | TET máx | overruns |
|---|---|---|---|---|
| 500 µs | 1.000 | 7.1 µs | 199 µs | 0 % |
| 100 µs | 1.000 | 3.7 µs | 590 µs | 0 % |
| 50 µs  | 1.000 | 3.4 µs | 509 µs | 0 % |
| 10 µs  | 1.000 | 2.4 µs | 849 µs | 1 % |
| 5 µs | 1.000 | 1.6 µs | 3 125 µs | 5 % |
| 1 µs | **0.685** | 1.0 µs | **36 473 µs** | 57 % |

Lectura: QUARC con fast timer **mantiene RTF=1 hasta ~5 µs** (con 1–5 % de overruns puntuales
que aún recupera) y solo **colapsa en 1 µs** (RTF 0.685, 57 %). Es decir, alcanza
**esencialmente el mismo paso fino de tiempo real que la RT Box** (~5–10 µs). La diferencia
decisiva está en el **peor caso**: el `TET_max` crece de ~200 µs a **36 ms** al forzar la tasa,
por el no-determinismo de Windows, mientras el jitter de la box permanece sub-µs. 

Conclusión final del sustrato: en **capacidad de tasa** QUARC (PC potente + fast timer) ≈ RT
Box; en **determinismo** (cota del peor caso) la RT Box es netamente superior. El fast timer
iguala el throughput a costa de una cola de latencia no acotada y alto uso de CPU.

---

## 8. Jitter según el timebase: QSM (software) vs QHW (hardware HIL) vs RT Box

En el punto de operación (2 ms, sin overruns en ninguno) el **jitter del instante de muestreo**
depende de qué disciplina el reloj del lazo, no del experimento:

| modalidad | timebase del lazo | jitter @ 2 ms |
|---|---|---|
| RT Box | timer de hardware (bare-metal) | sub-µs |
| QHW (planta real) | `HIL Read Encoder Timebase` (timer de la tarjeta HIL) | ~36–70 µs |
| QSM (planta simulada) | timer de software de Windows (sin hardware) | ~320 µs |

Medido en E2-QSM a 2 ms (fast timer OFF): RTF=1.000, TET med 9.5 µs, TET máx 237 µs, 0
overruns, **jitter 319 µs**. Frente a E2-QHW (mismo kernel QUARC, misma tasa): jitter ~36 µs.
La diferencia (~×5–10) **no** es el cómputo (el TET es igual de bajo) ni el fast timer (apagarlo
solo bajó el TET máx de 557 a 237 µs; el jitter siguió en ~320 µs): es que **QHW tiene un
timebase de hardware** (la tarjeta HIL del QUBE disciplina el muestreo) y **QSM no** (depende
del reloj de software del SO). Coincide con la recomendación de Quanser de usar un hardware
timebase para tiempos de muestreo ≤ 2 ms [1].

Ordenamiento del determinismo, coherente con §4 y §7: **RT Box (hardware bare-metal) ≪ QHW
(timebase HIL) ≪ QSM (software Windows).** Cuanto más disciplina de hardware tiene el reloj,
menor el jitter. El mismo comportamiento aplica a E1-QSM y E3-QSM: es una propiedad del
sustrato (software puro sin timebase), no del experimento.

> **Nota metodológica:** para las corridas de punto de operación (2 ms) conviene **desactivar
> el fast system timer** (solo se necesita para el barrido sub-ms); con él apagado el TET máx
> baja y el jitter reportado es el representativo del sustrato QUARC estándar.

---

## 9. Barrido de lazo cerrado (E3-QSM) y comparacion abierto/cerrado y box/QUARC

Barrido con fast timer del modelo de lazo cerrado (planta + EKF + swing-up + LQI):

| paso base | RTF | overruns | paso real logrado |
|---|---|---|---|
| 500 µs | 1.000 | 0 % | 500 µs |
| 100 µs | 1.000 | 0 % | 100 µs |
| 50 µs  | 1.000 | 0 % | 50 µs |
| 10 µs  | 1.000 | 2 % | 10 µs |
| 5 µs | 1.000 | 7 % | 5 µs |
| 1 µs | **0.319** | 100 % | 3.13 µs |

E3 (cerrado) mantiene RTF=1 hasta ~5 µs y colapsa en 1 µs, **mismo umbral que E1 (abierto)**,
pero colapsa **más fuerte** (RTF 0.319 vs 0.685 de E1; 100 % vs 57 % de overruns): el lazo
cerrado, más pesado, cae más abajo al pasar el límite.

**Contraste con la RT Box — el hallazgo fino:**

| | RT Box (bare-metal) | QUARC-QSM (fast timer, PC) |
|---|---|---|
| Umbral lazo ABIERTO (E1/E2) | ~5–10 µs | ~5 µs |
| Umbral lazo CERRADO (E3) | ~16–17 µs | ~5 µs |
| ¿Por qué cerrado > abierto? | CPU embebido lento → el TET del EKF (~16 µs) domina y overrunea antes | CPU del PC tan rápido que el EKF es despreciable; ambos topan en el **mismo** piso de timer/jitter |

Lectura: en la **RT Box** el costo de cómputo del EKF es **visible** — el lazo cerrado overrunea
en un paso mucho más grueso (16 µs) que el abierto (5–10 µs), porque el procesador embebido es
lento y el EKF sube el TET. En **QUARC sobre PC** el CPU es tan potente que el cómputo del EKF es
**despreciable**: abierto y cerrado topan igual (~5 µs), limitados por el timer/jitter del SO, no
por el cómputo. Es decir, la penalización de cerrar el lazo que se ve claramente en la box
**desaparece** en QUARC por el exceso de potencia del PC — otra manifestación de *compute-bound*
(box) vs *timer/jitter-bound* (QUARC). La única huella del lazo cerrado en QUARC es que colapsa
más severamente una vez cruzado el piso (RTF 0.32 vs 0.68 en 1 µs).

Fidelidad E3-QSM en el punto de operación (2 ms): swing-up llega a Er, captura y balancea firme
(α ±0.12°, θ std 0.67°), incluso más apretado que QHW por ser modelo limpio sin perturbaciones.

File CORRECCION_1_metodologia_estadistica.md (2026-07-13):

# Corrección 1 — Validez estadística de las comparaciones (Cap. 5)

**Observación del ingeniero.** Las comparaciones del Capítulo 5 se apoyaban en una sola corrida por
fase (swing-up / balance), sin repeticiones. Se pide complementar con un análisis cuantitativo de
error por fase y una banda de confianza que caracterice la dispersión natural del sistema real, de
modo que el gemelo se valide mostrando que predice el comportamiento dentro de los márgenes de
variabilidad operativa (n = 10 corridas independientes).

Este documento reúne la metodología aplicada, los datos, tablas, valores y figuras nuevos, y el
mapa de dónde reemplazar/añadir en `Documento/TESIS`. Todo se generó sobre los `.mat` nuevos de
`\Scape` (10 repeticiones QHW por experimento) y es reproducible con `analisis_bandas_tesis.m`.

---

## 1. Fundamento estadístico

### 1.1 Por qué solo la planta real se repite (y los modelos no)

Las modalidades SIM, QSM y RTB ejecutan el **mismo** modelo analítico M1 sobre un integrador de paso
fijo con condición inicial y entrada deterministas. Un integrador determinista con CI y entrada
fijas produce una trayectoria idéntica en cada ejecución: no hay ruido de proceso, ni de medición,
ni condiciones iniciales no repetibles. Por construcción su desviación estándar entre corridas es
cero (se verificó que `fid_E1_qsm` y `fid_E1_sim` coinciden salvo un canal de envolvente), de modo
que repetir no aporta información. La variabilidad que exige tratamiento estadístico es una
**propiedad del sistema físico real** (fricción estática, ruido eléctrico y del motor, condición
inicial del cable, nivelación). Por eso las repeticiones (n = 10) son solo de la planta real (QHW).

Excepción que conviene nombrar para cerrar la observación por ambos lados: en los sustratos de
tiempo real (QHW y RTB) las **métricas temporales** (TET, jitter, overruns) sí varían corrida a
corrida porque dependen del planificador del sistema operativo, no del modelo; esa variabilidad ya
se caracteriza aparte. La distinción es: la **trayectoria** del modelo es determinista (no se
repite); la **temporización** en tiempo real sí es estocástica (ya caracterizada).

### 1.2 Definición de la banda y de la significancia

Con las n = 10 corridas reales alineadas por su evento (§1.3) y remuestreadas a una malla común
`t_k`, para cada señal (θ, α) se calcula:

- **Media de conjunto** `μ(t_k) = (1/n) Σ_i s_i(t_k)`.
- **Desviación típica muestral** `σ(t_k) = sqrt( (1/(n−1)) Σ_i (s_i(t_k)−μ(t_k))² )`.
- **Banda operativa 95 %** `μ(t_k) ± 1.96·σ(t_k)`. Es una banda de predicción: dónde cae una corrida
  individual del sistema real. Responde a "márgenes de variabilidad operativa". El factor **1.96**
  es el cuantil 0.975 de la normal estándar: para una variable aproximadamente normal, el intervalo
  `μ ± 1.96σ` contiene el 95 % de las realizaciones (2.5 % en cada cola).
- **Intervalo de confianza de la media 95 %** `μ(t_k) ± t_{9,0.975}·σ(t_k)/√n`, con
  **t_{9,0.975} = 2.262** (distribución t de Student, n−1 = 9 grados de libertad). Cuantifica la
  incertidumbre en la estimación de la trayectoria media; se estrecha con √n. Da la significancia
  estadística de la media.

Se usa t de Student (no z = 1.96) para el IC de la media porque σ se estima de la propia muestra
con n = 10 (pequeña); con muestras pequeñas la t corrige el sub-dimensionamiento de σ. Para la banda
operativa se usa el cuantil normal 1.96 porque describe la dispersión por muestra de la población,
no la incertidumbre del promedio.

- **Cobertura del modelo** por fase: fracción de muestras en que la trayectoria determinista del
  modelo cae dentro de `μ ± 1.96σ`. Es la validación directa que pide el ingeniero: si el gemelo cae
  dentro de la banda operativa la mayor parte del tiempo, predice el comportamiento dentro de los
  márgenes de variabilidad del real.

### 1.3 Alineación por evento (imprescindible antes de promediar)

Promediar corridas mal alineadas mezcla fases distintas e infla artificialmente σ. Cada experimento
tiene su ancla:

- **E1 (caída libre):** el péndulo cuelga a 180°, se **alza a mano** hasta ~0° (arriba), se sostiene
  un tiempo **variable** y se suelta; a partir de ahí cae en oscilación amortiguada. El instante de
  soltada `t0_i` cae en momentos distintos por corrida (media 6.37 s, σ = 0.79 s, rango 5.6–8.1 s).
  Se detecta como el fin del tramo sostenido cerca de arriba (`|wrap(α)| < 0.35` sostenido, con
  salida al superar 0.5 rad) y cada corrida se reancla a `t − t0_i = 0`. Dos de las diez corridas
  (4 y 9) caen hacia el lado opuesto (cuelgan en −π); se pliega el signo respecto al colgado para
  agruparlas con las demás sin sesgar la banda.
- **E2 (forzado):** el comando `Vm` es determinista e idéntico entre corridas; se alinea por
  correlación cruzada de `Vm`. Los desfases resultaron **cero** en las diez, así que las corridas ya
  estaban sincronizadas por el comando.
- **E3 (lazo cerrado):** la señal `mode` (0 = swing-up, 1 = balance) marca la **captura** con
  precisión. El instante de captura es muy repetible (media 2.733 s, σ = 0.003 s), de modo que la
  fase de balance queda alineada al instante de conmutación.

---

## 2. Resultados nuevos por experimento

> Nota general: los `.mat` nuevos de `\Scape` dan valores absolutos distintos a los de la tabla
> actual de la tesis (que provenían de la corrida única antigua). Todos los valores de abajo se
> recalcularon con **un único criterio consistente** para las cuatro modalidades y el 3D.

### 2.1 E1 — Caída libre  (figura `E1_banda_fn.png`)

Banda muy estrecha: **σ_α ≈ 2°** (ancho de banda ≈ 7.8°). La caída libre es altamente repetible.
El gemelo analítico, **sembrado desde el estado medio de soltada** (α₀, dα₀ medidos, no desde
reposo), sigue a la media real ≈ 2 s y luego deriva lentamente en fase por la brecha de frecuencia.
La frecuencia natural y el amortiguamiento se midieron con el método de decremento del propio
proyecto (`ver_E1_qhw`), aplicado por igual a real y modelos:

| Modalidad | f_n [Hz] | brecha f_n | ζ |
|---|---|---|---|
| QHW real (M0, n=10) | **2.387 ± 0.016** (IC95 ±0.012) | — | 0.0378 |
| QSM (RK4) | 2.187 | −8.4 % | 0.0568 |
| SIM (RK4) | 2.187 | −8.4 % | 0.0568 |
| RTB (Euler) | 2.220 | −7.0 % | 0.0525 |
| 3D (M2) | 1.938 | −18.8 % | 0.0644 |

Lecturas: (i) el real es muy repetible (CV = 0.7 %); (ii) todos los modelos **sub-predicen** la
frecuencia; (iii) RTB (Euler) queda levemente por encima de QSM/SIM (RK4); (iv) **el 3D es el que
más se aleja en frecuencia (−18.8 %)**, no el más fiel. Esto invierte la afirmación de la tesis
actual ("el 3D reproduce casi exacto la frecuencia real, +0.6 %"), que era de los datos antiguos.

> **Punto que requiere tu confirmación (ya señalado en el chat).** El f_n real nuevo (2.39 Hz)
> difiere del de la tesis (1.82 Hz), y el 3D pasa de "el mejor" a "el peor" en frecuencia. El valor
> absoluto de f_n es además sensible a la ventana de amplitud. Si confirmas los `.mat` nuevos, la
> narrativa de E1 que decía que el 3D valida por su cercanía en frecuencia debe reescribirse: ahora
> el analítico queda **entre** el real y el 3D.

### 2.2 E2 — Respuesta forzada  (figura `E2_banda_fn.png`)

Banda de θ estrecha: **σ_θ ≈ 1.4°**. En los datos nuevos el péndulo **gira** (da vueltas completas),
por lo que α no es comparable punto a punto entre corridas (σ_α_wrap ≈ 19°); la variable robusta es
el brazo θ. El acuerdo de amplitud de θ (desviación típica de la oscilación) es excelente:

| Modalidad | std θ [°] | error amplitud | RMSE_θ vs real [°] | cobertura banda |
|---|---|---|---|---|
| QHW real (n=10) | 57.46 | — | — | — |
| QSM = SIM (RK4) | 58.57 | +1.9 % | 16.18 | 25 % |
| RTB (Euler) | 57.57 | +0.2 % | 19.22 | 24 % |
| 3D (M2) | 59.83 | +4.1 % | 15.08 | 27 % |

El RMSE punto a punto (15–19°) está dominado por la **deriva de fase** del barrido, no por amplitud
(la misma distinción que ya explica la tesis para E2). RTB/Euler tiene el mayor RMSE. La cobertura
es baja (24–27 %) porque la banda es muy estrecha (σ = 1.4°): incluso desfases pequeños salen de una
banda tan fina, lo cual es coherente con reportar la **amplitud** como métrica y no el RMSE.

### 2.3 E3 — Lazo cerrado  (figura `E3_banda_fn.png`)

Es el resultado más contundente para la observación. En balance el gemelo cae **dentro de la banda
operativa real el 97–100 % del tiempo**. Métricas por fase (ventana estacionaria W2 = captura+1 a
captura+3 s; ventana con asentamiento W1 = captura a captura+2.5 s):

| Índice | QHW real (n=10) | QSM=SIM | RTB (Euler) | 3D (M2) |
|---|---|---|---|---|
| Tiempo de captura [s] | **2.733 ± 0.003** (IC95 ±0.002) | 2.732 | 2.716 | 2.66 |
| Vaivenes de swing-up | **7 (σ=0)** | 7 | 7 | 7 |
| RMS α balance W2 [°] | 0.185 | 0.160 | 0.093 | — |
| RMS α balance W1 [°] | 2.882 | 2.276 | — | — |
| std θ balance W2 [°] | 1.87 | 1.94 | 0.55 | — |
| RMSE α vs real, W2 [°] | — | 0.168 | 0.170 | 0.255 |
| e_max α vs real, W2 [°] | — | 0.404 | 0.431 | 0.650 |
| Cobertura banda (balance) | — | **100 %** | 98 % | (dentro) |
| NIS medio (balance) | 1.25 | 1.69 | 1.12 | — |
| Esfuerzo control ∫Vm²dt [V²·s] | 5.04 | 8.86 | 12.05 | — |

Lecturas: (i) la captura es extraordinariamente repetible (σ = 3 ms); (ii) **todas las modalidades
capturan en 7 vaivenes**, igual que el real (esto retira el "hallazgo" antiguo, §3); (iii) en balance
el error del gemelo (RMSE ≤ 0.17°, e_max ≤ 0.43°) es muy inferior al ancho de la banda real, y su
cobertura llega al 100 %; (iv) el gemelo real dispersa un poco más (RMS 0.185°) que el modelo
determinista (0.160°), como es de esperar por el ruido físico ausente en el modelo; (v) el modelo
usa más esfuerzo de control que la media real (traqueteo determinista frente a promedio que suaviza
el ruido), y RTB/Euler el que más.

---

## 3. Corrección del "vaivén de más" y de la sección R.5 (Hallazgos)

**Qué decía la tesis (sec:res:hallazgos).** Con la corrida única antigua, el analítico QSM/SIM (RK4)
capturaba en 3.13 s con **8 vaivenes**, mientras el real, RTB y 3D lo hacían en 7. Sobre eso se
construyó toda una sección: el vaivén de más se atribuía (a) al integrador (RK4 vs Euler) y (b) a la
idealización del modelo, con un barrido de la ganancia de bombeo `ke`.

**Qué muestran los datos nuevos.** Con `fid_E3_qsm.mat` actualizado, el analítico captura en
**2.73 s con 7 vaivenes**, igual que el real (2.733 ± 0.003 s), RTB y 3D. El vaivén de más era
consecuencia de **parámetros desactualizados y un signo** en el modelo analítico de Simulink, **no
del solver**. La premisa de la sección R.5 es, por tanto, falsa.

**Qué hacer.** Retirar la explicación RK4-vs-Euler y el barrido de `ke` como causa determinante.
Como ahora **todas las modalidades hacen el mismo número de oscilaciones (7)**, no hay anomalía que
explicar y la sección extensa deja de tener sentido. Se reemplaza por una nota breve de consistencia
(texto listo en §5). Si se quiere conservar rastro, el efecto RK4/Euler puede quedar como
**observación menor** (el conteo de swing-up es una decisión por umbral sensible al método), pero
**sin** sostener que el analítico "falla" con un vaivén de más, porque ya no ocurre.

Figuras que quedan sin uso al retirar R.5: `hallazgo_swingup_rk4_vs_euler.png`,
`hallazgo_swingup_barrido_ke.png`, `hallazgo_swingup_ke52_vs_real.png`.

---

## 4. Coherencia de métricas Metodología ↔ Resultados (observación de "métricas")

La Metodología (`sec:met:metricas`, Tabla `tab:metricas`) define métricas que **Resultados no
reportaba**. Esto es lo que conviene cerrar:

| Métrica definida (Metodología) | ¿Se usaba en Resultados? | Acción |
|---|---|---|
| RMSE_θ, RMSE_α (eq:rmse) | Sí (E3); E1/E2 lo evitan con justificación | Mantener; ahora **por fase y con banda** |
| Error máximo e_max (eq:emax) | **No aparecía** | Añadido: E3 balance e_max α = 0.40–0.65° |
| Coherencia temporal τ* (eq:…) | Sí (E2, mirroring) | Mantener |
| f_n, ζ (eq:logdec) | Sí (E1) | Mantener; ahora con dispersión n=10 |
| Brecha de fidelidad Δ_M1 (eq:brecha) | **No se computaba como tal** | Añadido: Δ_M1 = RMSE(M1:M0) − RMSE(3D:M0) = 0.168 − 0.255 = **−0.087°** en balance (el analítico es incluso mejor que el 3D en el régimen de operación) |
| Índices lazo cerrado: t_captura, RMS α, ∫Vm²dt | t_captura y RMS α sí; **∫Vm²dt no** | Añadido: ∫Vm²dt real 5.04 / M1 8.86 / RTB 12.05 V²·s |
| Jitter, overruns, lost, latencia, RTF, NIS | Sí | Mantener |

Conclusión para el ingeniero: se computan ahora **todas** las métricas definidas (incluidas e_max,
Δ_M1 y ∫Vm²dt), y las de error se dan **por fase** (swing-up / balance) y con banda estadística.

---

## 5. Texto y LaTeX listos para integrar

### 5.1 Nota metodológica (añadir en `sec:met:metricas`, tras eq:brecha o en un párrafo nuevo)

> Para dotar de validez estadística a las comparaciones de fidelidad, cada ensayo con la planta real
> se repite $n=10$ veces de forma independiente. Como los modelos (M1 en cualquier sustrato y el 3D)
> son deterministas —integrador de paso fijo con condición inicial y entrada fijas—, sus trayectorias
> no varían entre ejecuciones y no se repiten; la variabilidad que se caracteriza es la del sistema
> físico. Alineadas las diez corridas por su evento característico (soltada en E1, comando en E2,
> conmutación a balance en E3), se calcula la media de conjunto $\mu(t)$ y la desviación típica
> $\sigma(t)$, y se define la banda operativa $\mu(t)\pm 1.96\,\sigma(t)$, que contiene el $95\%$ de
> las realizaciones del real bajo dispersión aproximadamente normal. La significancia de la media se
> expresa con su intervalo de confianza $\mu(t)\pm t_{9,0.975}\,\sigma(t)/\sqrt{n}$, con
> $t_{9,0.975}=2.262$. La fidelidad del gemelo se evalúa por la cobertura —fracción de muestras de
> cada fase en que su trayectoria cae dentro de la banda— y por las métricas de error de la
> Ec.~\eqref{eq:rmse}–\eqref{eq:emax} calculadas frente a $\mu(t)$ y separadas por fase.

### 5.2 Reemplazos de tablas en `04_Resultados_rv.tex`

**Tabla E1 (`tab:res:e1`)** — reemplazar por:

```latex
\begin{table}[H]
  \centering
  \caption{Caída libre (E1): frecuencia natural y amortiguamiento por modalidad. El real es la media
  de $n=10$ corridas (intervalo de confianza al 95\%).}
  \label{tab:res:e1}
  \begin{tabular}{@{}lccc@{}}
    \toprule
    Modalidad & $f_n$ [Hz] & $\zeta$ & brecha $f_n$ \\
    \midrule
    QHW (real, $M_0$, $n=10$) & $2.387\pm0.012$ & 0.0378 & --- \\
    QSM (RK4) & 2.187 & 0.0568 & $-8.4\%$ \\
    SIM (RK4) & 2.187 & 0.0568 & $-8.4\%$ \\
    RTB (Euler) & 2.220 & 0.0525 & $-7.0\%$ \\
    \midrule
    3D ($M_2$, referencia) & 1.938 & 0.0644 & $-18.8\%$ \\
    \bottomrule
  \end{tabular}
\end{table}
```

**Tabla E2 (`tab:res:e2`)** — reemplazar por (amplitud de $\theta$, que es la variable robusta con
la excitación nueva):

```latex
\begin{table}[H]
  \centering
  \caption{Respuesta forzada (E2): acuerdo de amplitud del brazo $\theta$ (desviación típica de la
  oscilación) frente al real ($n=10$) y RMSE temporal. El RMSE lo domina la deriva de fase del
  barrido, no la amplitud.}
  \label{tab:res:e2}
  \begin{tabular}{@{}lccc@{}}
    \toprule
    Modalidad & std $\theta$ [$^\circ$] & error amplitud & RMSE$_\theta$ [$^\circ$] \\
    \midrule
    QHW real ($n=10$) & 57.46 & --- & --- \\
    QSM = SIM (RK4) & 58.57 & $+1.9\%$ & 16.18 \\
    RTB (Euler) & 57.57 & $+0.2\%$ & 19.22 \\
    \midrule
    3D ($M_2$) & 59.83 & $+4.1\%$ & 15.08 \\
    \bottomrule
  \end{tabular}
\end{table}
```

**Tabla E3 (`tab:res:e3`)** — reemplazar por (con dispersión del real, dos ventanas de balance y las
métricas antes ausentes):

```latex
\begin{table}[H]
  \centering
  \caption{Lazo cerrado (E3): índices por modalidad. El real es la media de $n=10$ corridas. En
  balance el gemelo cae dentro de la banda operativa real el 97--100\% del tiempo.}
  \label{tab:res:e3}
  \begin{tabular}{@{}lccccc@{}}
    \toprule
    Índice & QHW real & QSM=SIM & RTB & 3D \\
    \midrule
    $t_{\text{captura}}$ [s] & $2.733\pm0.002$ & 2.732 & 2.716 & 2.66 \\
    Vaivenes swing-up & 7 & 7 & 7 & 7 \\
    RMS $\alpha$ balance (estac.) [$^\circ$] & 0.185 & 0.160 & 0.093 & --- \\
    std $\theta$ balance (estac.) [$^\circ$] & 1.87 & 1.94 & 0.55 & --- \\
    RMSE $\alpha$ vs real [$^\circ$] & --- & 0.168 & 0.170 & 0.255 \\
    $e_{\max}\,\alpha$ vs real [$^\circ$] & --- & 0.404 & 0.431 & 0.650 \\
    Cobertura banda balance & --- & 100\% & 98\% & dentro \\
    NIS medio & 1.25 & 1.69 & 1.12 & --- \\
    $\int V_m^2\,dt$ [V$^2$s] & 5.04 & 8.86 & 12.05 & --- \\
    \bottomrule
  \end{tabular}
\end{table}
```

### 5.3 Reemplazo de la sección R.5 (`sec:res:hallazgos`)

Retirar el contenido actual (8 vaivenes, RK4-vs-Euler, barrido `ke`) y sustituir por una nota breve:

```latex
\section{Consistencia del comportamiento en lazo cerrado}
\label{sec:res:hallazgos}

Con las diez repeticiones de cada modalidad, el comportamiento de lazo cerrado resultó consistente
entre sustratos y frente al real. Las cuatro modalidades capturan el péndulo en \textbf{siete
vaivenes} y en un tiempo prácticamente idéntico (real $2.733\pm0.003$~s; QSM/SIM $2.732$~s; RTB
$2.716$~s; 3D $2.66$~s), y en la fase de balance sus trayectorias caen dentro de la banda operativa
del real entre el $97$ y el $100\%$ del tiempo, con un RMSE de $\alpha$ inferior a $0.17^\circ$ y un
error máximo por debajo de $0.65^\circ$. No se observan diferencias de conteo de vaivenes atribuibles
al método de integración: RK4 (QSM/SIM) y Euler (RTB) coinciden en siete. El esfuerzo de control en
balance es mayor en el gemelo determinista que en la media del real ($\int V_m^2\,dt$ de $8.9$ y
$12.1$~V$^2$s en QSM y RTB frente a $5.0$~V$^2$s del real), lo que refleja el promediado del ruido
en la media de las diez corridas reales y no una diferencia de estabilidad.
```

> Nota: si en alguna corrida antigua figuraba el conteo de 8 vaivenes, provenía de un modelo
> analítico con parámetros desactualizados y un signo, ya corregido; no es un efecto del solver.

### 5.4 Ajuste en la lectura cruzada (`sec:res:brecha`) y E1/E2 sobre el 3D

La frase "en caída libre el modelo tridimensional reproduce la frecuencia natural del real casi
exactamente ($0.6\%$)… mejor que el analítico" ya **no** es válida con los datos nuevos: el 3D queda
a $-18.8\%$ y el analítico a $-8.4\%$. Reescribir para reflejar que el analítico es más fiel en
frecuencia que el 3D, y que ninguno es uniformemente superior. (Sujeto a tu confirmación del punto
de §2.1.)

---

## 6. Figura α unwrap vs α wrap (lazo cerrado)  → `E_alpha_wrap_unwrap.png`

Muestra, sobre el swing-up de E3, la señal continua `α` (encoder, desenvuelta: acumula las vueltas y
llega a $-540°$) y su versión envuelta `α_wrap = mod(α+π, 2π) − π ∈ [−180°, 180°]`, solapadas. Ambas
coinciden en la rama principal (cerca de arriba, `|α|<180°`); el pliegue de `wrap` ocurre en el
fondo (`±180°`), lejos del punto de operación del balance (`α=0`, arriba). El lazo cerrado realimenta
`α_wrap`: así "arriba" es siempre 0 sin importar cuántas vueltas dio el péndulo, y la discontinuidad
de $\pm\pi$ queda en el colgado, donde no afecta a la regulación. Sugerencia de ubicación: en
Desarrollo, junto a la descripción del observador/control, o en Metodología al definir la convención
de $\alpha$.

---

## 7. Archivos generados

Figuras (en `figs/resultados/`): `E1_banda_fn.png`, `E2_banda_fn.png`, `E3_banda_fn.png`,
`E_alpha_wrap_unwrap.png`. Datos intermedios: `E1_stats.mat`, `E2_stats.mat`, `E3_stats.mat`.
Script reproducible: `analisis_bandas_tesis.m`.

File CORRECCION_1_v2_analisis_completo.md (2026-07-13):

# Corrección 1 (v2) — Validez estadística, análisis por fase/zona y contraste de hipótesis

Reemplaza a la v1. Incorpora: (a) corrección del f_n de E1 y del "3D outlier"; (b) auditoría y
arreglo de signos entre modalidades; (c) modalidades separadas y consistentes en todas las figuras;
(d) E2 por segmentos de Vm; (e) E3 por zonas (swing-up / transición / balance); (f) barras
estadísticas con IC/σ para E1, E2, E3; (g) contraste explícito de la hipótesis (Sec. 2.11); (h) mapa
de cambios en Desarrollo, Resultados y Conclusiones. Todo reproducible con `analisis_bandas_tesis.m`.

---

## 0. Correcciones respecto de la v1 (importantes)

1. **f_n de E1 — el 3D NO es un outlier.** En la v1 el 3D salía a −18.8 %; era un artefacto de medir
   f_n promediando toda la cola de la caída (cada modalidad pasa distinto tiempo en cada amplitud, y
   el periodo del péndulo depende de la amplitud). Midiendo el periodo **a amplitud igualada** (o el
   f_n lineal de pequeña amplitud, 8–25°), **todas las modalidades coinciden**: QSM = SIM = RTB = 3D
   = 2.203 Hz, y el real 2.432 Hz. La brecha es **uniforme −9.4 %** y es del modelo, no de ninguna
   modalidad en particular. La figura `E1_periodo_amplitud.png` lo demuestra: las cinco curvas se
   solapan a amplitud grande y solo el real se adelanta ~9 % en pequeña amplitud.

2. **Signos entre modalidades.** Auditoría por correlación con el real: en E3 el **θ del 3D** estaba
   invertido y el **α de QSM y RTB** invertido (la dirección del swing-up es arbitraria y algunas
   modalidades registran α con signo opuesto). Se corrige alineando el signo de **cada señal de cada
   modalidad** al real por correlación (práctica que el propio proyecto ya usa en
   `comparar_real_modelo3d`). En E2 los signos ya coincidían.

3. **Modalidades separadas y consistentes.** Cada modalidad se grafica y tabula por separado: QHW
   real (M0), QSM (RTS QUARC del analítico), SIM (Simulink convencional del analítico), RTB (RT Box),
   3D (M2). QSM y SIM dan trayectoria **idéntica** (mismo M1, mismo RK4; solo cambia el sustrato de
   ejecución), por eso comparten curva rotulada "QSM=SIM", pero son **filas separadas** en las tablas.
   En todos los paneles (α y θ) aparecen las cuatro modalidades.

---

## 1. Fundamento estadístico (igual que v1, resumen)

n = 10 corridas independientes solo de la planta real; los modelos son deterministas (σ=0 por
construcción) y no se repiten. Banda operativa **μ ± 1.96σ** (1.96 = cuantil 0.975 normal → 95 % de
las realizaciones); IC de la media **μ ± 2.262·σ/√n** (t de Student, 9 g.l.). Cobertura = fracción
de muestras de cada fase dentro de la banda. Alineación por evento: soltada (E1), comando Vm (E2),
conmutación `mode` (E3).

---

## 2. E1 — Caída libre  (figuras: `E1_banda.png`, `E1_barras.png`, `E1_periodo_amplitud.png`)

Banda muy estrecha (σ_α ≈ 2°): la caída es altamente repetible. Frecuencia natural y amortiguamiento
medidos **igual para todos** (periodo en el régimen lineal de pequeña amplitud, 8–25°):

| Modalidad | f_n [Hz] | brecha | ζ |
|---|---|---|---|
| QHW real (M0, n=10) | **2.432 ± 0.017** (IC95) | — | **0.0261 ± 0.0006** (IC95) |
| QSM (RTS QUARC, RK4) | 2.203 | −9.4 % | 0.0274 |
| SIM (Simulink conv., RK4) | 2.203 | −9.4 % | 0.0274 |
| RTB (RT Box, Euler) | 2.203 | −9.4 % | 0.0255 |
| 3D (M2) | 2.203 | −9.4 % | 0.0255 |

Lecturas: (i) el real es muy repetible (CV = 0.7 % en f_n); (ii) **todos los modelos convergen al
mismo f_n lineal (2.203 Hz)** — el 3D no difiere de los demás; (iii) la brecha −9.4 % es del modelo
(péndulo real ~9 % más rápido en pequeña amplitud), uniforme; (iv) el amortiguamiento coincide
(ζ ≈ 0.026 en todos). La figura de barras lleva **IC95 del real en f_n y en ζ**. La figura
periodo-vs-amplitud muestra que a amplitud grande (>100°) las cinco curvas se solapan y la separación
solo aparece en pequeña amplitud.

> Esto **corrige** la tabla de la tesis actual (real 1.82, 3D +0.6 % "el más fiel"): con los datos
> nuevos y un método consistente, el 3D no es más fiel que el analítico en frecuencia; todos empatan.

---

## 3. E2 — Respuesta forzada  (figuras: `E2_banda.png`, `E2_segmentos.png`)

Banda de θ estrecha (σ_θ ≈ 1.4°). α gira (da vueltas) → no comparable punto a punto; θ es la variable
robusta. Las cuatro modalidades se muestran con signo alineado. Se analiza el Vm por **tres
segmentos** de carácter distinto:

| Segmento (Vm) | saturación tope | RMSE_θ QSM=SIM | RMSE_θ RTB | RMSE_θ 3D | error amplitud (QSM/RTB/3D) |
|---|---|---|---|---|---|
| Escalones (1–10 s) — choca ±135° | 19 % del tramo | 20.8° | 29.3° | 11.8° | −2.8 % / −10.7 % / +3.0 % |
| Barrido lento-medio (10–24 s) | 0 % | 18.4° | 18.2° | 21.0° | +9.4 % / +16.0 % / +6.1 % |
| Barrido rápido (24–33 s) | 0 % | 7.7° | 7.9° | 7.4° | −2.4 % / −1.7 % / −1.8 % |

Lecturas: (i) en la zona de **escalones que chocan el tope**, el **3D es el más fiel** (RMSE 11.8°,
amplitud +3 %) porque modela el contacto con el límite mecánico, y **RTB/Euler el peor** (29.3°,
−10.7 %); (ii) en el **barrido lento** RTB/Euler **sobreestima** la amplitud (+16 %), el efecto de
inyección de energía numérica del Euler; (iii) en el **barrido rápido** (pequeña amplitud) las cuatro
coinciden (~±2 %). El RMSE temporal (15–20°) lo domina la deriva de fase del barrido, no la amplitud.

---

## 4. E3 — Lazo cerrado por zonas  (figuras: `E3_banda.png`, `E3_zonas.png`)

Controlador híbrido swing-up (bombeo de energía) → conmutación en la banda de captura ±17° → balance
LQI sobre el estado estimado. Se compara la maniobra **completa** y por **tres zonas**: swing-up,
transición (al cruzar 17° hasta asentarse en 3°) y balance estable. Todas las modalidades con signo
alineado.

| Zona / índice | QHW real (n=10) | QSM=SIM | RTB | 3D |
|---|---|---|---|---|
| **Swing-up** captura [s] | 2.733 ± 0.003 (IC95 ±0.002) | 2.732 | 2.716 | 2.676 |
| **Swing-up** vaivenes | 7 (σ=0) | 7 | 7 | 7 |
| **Transición** sobrepico α [°] | 16.6 ± 0.2 | 16.9 | 16.7 | 17.0 |
| **Transición** asentamiento 17°→3° [s] | 0.253 ± 0.004 | 0.284 | 0.104 | 0.094 |
| **Balance** RMS α (regulación) [°] | 0.268 ± 0.128 | 0.160 | 0.093 | 0.088 |
| **Balance** dispersión θ [°] | 2.18 | 1.94 | 0.55 | 0.15 |
| **Balance** NIS medio | 1.25 | 1.69 | 1.12 | — |
| **Balance** esfuerzo ∫Vm²dt [V²·s] | 5.04 | 8.86 | 12.05 | — |

Lecturas: (i) **todas capturan en 7 vaivenes** y en ~2.7 s (esto retira el "hallazgo" del vaivén de
más, §6); (ii) en la **transición**, el **QSM (analítico) es el que mejor iguala el asentamiento del
real** (0.284 vs 0.253 s), mientras RTB y 3D asientan "demasiado limpio" (0.09–0.10 s); (iii) en el
**balance**, el **real dispersa más** (RMS α 0.268°, std θ 2.18°) que los modelos (0.09–0.16°;
0.15–1.94°), porque los modelos no tienen el ruido y la fricción física — el gemelo regula incluso
más fino que el real, no peor. La banda operativa del real acota a los modelos en la fase estable.

---

## 5. Coherencia de métricas Metodología ↔ Resultados (obs. de "métricas")

Se computan ahora **todas** las métricas definidas en `sec:met:metricas` y que Resultados no
reportaba: **error máximo** e_max (E3 balance: 0.40–0.65°), **brecha de fidelidad**
Δ_M1 = RMSE(M1:M0) − RMSE(3D:M0) (≈ −0.09° en balance → el analítico no es peor que el 3D en el punto
de operación), y **esfuerzo de control** ∫Vm²dt (real 5.04 / QSM 8.86 / RTB 12.05 V²·s). Las métricas
de error se dan **por fase/zona** y con banda estadística.

---

## 6. Corrección del "vaivén de más" (R.5) — se retira

Con `fid_E3_qsm.mat` actualizado, el analítico captura en 2.73 s con **7 vaivenes**, igual que real,
RTB y 3D. El "8 vaivenes" antiguo era por parámetros desactualizados y un signo en el modelo de
Simulink, **no por el solver**. Toda la sección R.5 (RK4-vs-Euler, barrido `ke`) pierde premisa y se
reemplaza por una nota breve de consistencia (LaTeX en §8.3). Como observación menor puede mencionarse
que el conteo de swing-up es una decisión por umbral en principio sensible al integrador, pero **sin**
sostener que el analítico "falla", porque ya no ocurre.

---

## 7. Contraste explícito de la hipótesis (Sec. 2.11) — obs. del revisor

**Hipótesis (`sec:marco:hipotesis`):** «La ejecución en tiempo real … modifica de forma medible su
fidelidad respecto de la planta física … y ese efecto se relaciona con el jitter y los overruns …».

**Veredicto: se rechaza en su forma fuerte y se redefine.** La evidencia del Capítulo 5:
- Con el **integrador fijo**, QSM (RTS QUARC) y SIM (simulación convencional) dan trayectoria
  **idéntica** (E1 f_n 2.203 en ambos; E2 amplitud +1.9 %/idéntica; E3 balance idéntico). Es decir, la
  ejecución en tiempo real **por sí misma no modifica la fidelidad**.
- La única diferencia de trayectoria entre sustratos es **RTB (Euler) vs QSM/SIM (RK4)**, y su origen
  es el **método de integración**, no el jitter ni los overruns. De hecho **no hubo overruns** en el
  punto de operación, y el jitter (de microsegundos) no altera la trayectoria de un solver de paso
  fijo.
- Por tanto, el jitter/overruns gobiernan el **determinismo temporal** (Sección de RTS), no la
  fidelidad. La fidelidad la gobierna el **modelo** (brecha ~9 % con el real) y, en segundo orden, el
  **integrador**.

Redacción de la hipótesis redefinida (para la Discusión y Conclusiones): *el sustrato de tiempo real
no modifica de forma medible la fidelidad del gemelo (QSM ≡ SIM; RTB difiere solo por el integrador);
el jitter y los overruns condicionan el determinismo temporal, no la correspondencia con la planta.*

---

## 8. LaTeX listo para integrar

### 8.1 Tabla E1 (`tab:res:e1`)
```latex
\begin{table}[H]\centering
\caption{Caída libre (E1): frecuencia natural (lineal, régimen de pequeña amplitud) y
amortiguamiento por modalidad. El real es la media de $n=10$ corridas (IC 95\%).}
\label{tab:res:e1}
\begin{tabular}{@{}lccc@{}}\toprule
Modalidad & $f_n$ [Hz] & $\zeta$ & brecha $f_n$ \\ \midrule
QHW (real, $M_0$, $n=10$) & $2.432\pm0.017$ & $0.0261\pm0.0006$ & --- \\
QSM (RTS QUARC, RK4) & 2.203 & 0.0274 & $-9.4\%$ \\
SIM (Simulink conv., RK4) & 2.203 & 0.0274 & $-9.4\%$ \\
RTB (RT Box, Euler) & 2.203 & 0.0255 & $-9.4\%$ \\
3D ($M_2$) & 2.203 & 0.0255 & $-9.4\%$ \\ \bottomrule
\end{tabular}\end{table}
```

### 8.2 Tabla E3 (`tab:res:e3`)
```latex
\begin{table}[H]\centering
\caption{Lazo cerrado (E3) por zona. El real es la media de $n=10$ corridas (IC 95\%).}
\label{tab:res:e3}
\begin{tabular}{@{}lcccc@{}}\toprule
Índice & QHW real & QSM=SIM & RTB & 3D \\ \midrule
Captura [s] & $2.733\pm0.002$ & 2.732 & 2.716 & 2.676 \\
Vaivenes & 7 & 7 & 7 & 7 \\
Sobrepico transición [$^\circ$] & $16.6\pm0.2$ & 16.9 & 16.7 & 17.0 \\
Asentamiento $17^\circ\!\to\!3^\circ$ [s] & $0.253\pm0.004$ & 0.284 & 0.104 & 0.094 \\
RMS $\alpha$ balance [$^\circ$] & $0.268\pm0.128$ & 0.160 & 0.093 & 0.088 \\
Dispersión $\theta$ balance [$^\circ$] & 2.18 & 1.94 & 0.55 & 0.15 \\
NIS medio & 1.25 & 1.69 & 1.12 & --- \\
$\int V_m^2\,dt$ [V$^2$s] & 5.04 & 8.86 & 12.05 & --- \\ \bottomrule
\end{tabular}\end{table}
```

(La tabla E2 por segmentos está en §3; su versión LaTeX es análoga, una fila por segmento.)

### 8.3 Reemplazo de R.5 (`sec:res:hallazgos`)
```latex
\section{Consistencia del comportamiento en lazo cerrado}
\label{sec:res:hallazgos}
Con las diez repeticiones, el lazo cerrado resultó consistente entre sustratos y frente al real. Las
cuatro modalidades capturan en \textbf{siete vaivenes} y en un tiempo casi idéntico (real
$2.733\pm0.003$~s; QSM/SIM $2.732$~s; RTB $2.716$~s; 3D $2.676$~s); no hay diferencia de conteo
atribuible al integrador (RK4 y Euler coinciden en siete). En la transición a balance, el analítico
reproduce el asentamiento del real ($0.284$ frente a $0.253$~s) mejor que la RT Box o el 3D, que
asientan más rápido por carecer del ruido y la fricción físicos; en balance, el real dispersa algo más
(RMS de $\alpha$ de $0.268^\circ$) que los modelos ($0.09$--$0.16^\circ$), que regulan más fino al no
tener perturbaciones reales. El esfuerzo de control en balance es mayor en el gemelo determinista que
en la media del real ($8.9$ y $12.1$~V$^2$s en QSM y RTB frente a $5.0$~V$^2$s).
```

### 8.4 Párrafo de contraste de hipótesis (añadir al final de `sec:res:discusion`)
```latex
Con esto puede contrastarse la hipótesis (Sección~\ref{sec:marco:hipotesis}). Su forma fuerte
—que la ejecución en tiempo real modifica de forma medible la fidelidad y que ese efecto se relaciona
con el jitter y los overruns— no se sostiene: con el integrador fijo, QUARC en tiempo real (QSM) y la
simulación convencional (SIM) producen trayectorias idénticas, de modo que el tiempo real por sí mismo
no altera la fidelidad; la única diferencia de trayectoria entre sustratos proviene del método de
integración (Euler en la RT Box frente a Runge--Kutta), no del jitter ni de los overruns, que además
no se produjeron en el punto de operación. La hipótesis se redefine en consecuencia: el sustrato de
tiempo real gobierna el determinismo temporal (jitter, TET, RTF), mientras que la fidelidad la
gobiernan el modelo y, en segundo orden, el integrador, con independencia de la ejecución en tiempo
real.
```

---

## 9. Mapa de cambios por capítulo

### Desarrollo (`04_Desarrollo_rv.tex`)
- Añadir, junto al observador/control, la figura `E_alpha_wrap_unwrap.png` y una frase: el lazo
  realimenta $\alpha_{\text{wrap}}$ para que "arriba" sea siempre 0 y la discontinuidad de $\pm\pi$
  quede en el colgado, fuera del punto de operación.
- Si se menciona la validación 3D↔real, dejar claro que la comparación de fidelidad se cuantifica en
  Resultados con $n=10$ y banda.

### Resultados (`04_Resultados_rv.tex`)
- **§Fidelidad E1:** reemplazar `tab:res:e1` (§8.1) y las figuras por `E1_banda.png`,
  `E1_barras.png`, `E1_periodo_amplitud.png`. Reescribir el texto: el gap es uniforme ~9 % y el 3D no
  es más fiel en frecuencia; añadir que la comparación honesta es a amplitud igualada.
- **§Fidelidad E2:** añadir el análisis por segmentos (§3) con `E2_banda.png` y `E2_segmentos.png`;
  reportar el 3D como el más fiel en la zona de tope y el Euler como el que más sobreestima en el
  barrido lento.
- **§Fidelidad E3:** reemplazar `tab:res:e3` (§8.2) por la versión por zonas; figuras `E3_banda.png` y
  `E3_zonas.png`. Añadir la lectura por zonas (transición y balance).
- **§R.5:** reemplazar por §8.3 (se retira el vaivén de más).
- **§Discusión:** añadir el párrafo de hipótesis (§8.4). Ajustar "brecha ~5 %" a "~9 %".
- Añadir la nota metodológica de banda/n=10 (ver v1 §5.1) en `sec:met:metricas`.

### Conclusiones (`XX_Conclusiones_rv.tex`)
- **Corregir el párrafo de hallazgos** (líneas ~60–68): ya no procede decir que Euler/RK4 "cambia una
  decisión por umbral como el conteo de vaivenes" (ahora todas hacen 7). Sustituir por: las
  diferencias finas entre sustratos son de segundo orden (integrador) y no cambian el conteo de
  vaivenes ni la fidelidad; la comparación por zonas confirma que el analítico reproduce la transición
  y el balance del real dentro de su banda de variabilidad.
- **Actualizar** "cinco por ciento" → "alrededor del nueve por ciento" en la firma dinámica libre.
- **Añadir el veredicto explícito de la hipótesis** (una frase): *la hipótesis de partida
  (Sección~\ref{sec:marco:hipotesis}) se rechaza en su forma fuerte y se redefine: el tiempo real no
  modifica la fidelidad del gemelo (QSM ≡ SIM), sino su determinismo temporal; las diferencias de
  trayectoria entre sustratos provienen del integrador, no del jitter ni de los overruns.*

---

## 11. Addendum v3 — correcciones de α (E2), zonas de E3, θ y respuesta a la hipótesis

### 11.1 E2: α se muestra SIN envolver (corrige la v2)

El wrap de α solo tiene sentido en el lazo cerrado (swing-up+balance), donde el control necesita
"arriba = 0". En E1 (caída libre) y E2 (forzado) α es una señal **continua** del encoder y debe usarse
sin envolver. Al envolverla se creaba un falso "giro/divergencia". Con α **cruda**, en E2 el péndulo
oscila entre 120° y 234° (en torno al colgado 180°, **no gira**) y es **muy repetible entre corridas**:
σ_α ≈ 0.42° (más estrecha aún que θ). Por tanto α **sí** es comparable y es la variable principal de E2
(como en la tesis), junto con θ. Figuras `E2_banda.png` y `E2_corridas.png` regeneradas con α sin
envolver.

Métricas por segmento (RMSE, deg), con signo/nivel alineados al real:

| Segmento | RMSE α (QSM/RTB/3D) | RMSE θ (QSM/RTB/3D) |
|---|---|---|
| Escalones/tope | 21.4 / 19.3 / 11.7 | 20.8 / 29.3 / 11.8 |
| Barrido lento | 6.8 / 11.7 / 7.5 | 18.4 / 18.2 / 21.0 |
| Barrido rápido | 12.2 / 13.0 / 12.5 | 7.7 / 7.9 / 7.4 |

Hallazgo: en el **barrido lento** los modelos **sobrestiman la amplitud de α** (la std de α del real
ahí es ~5°, y los modelos 8–12°, +54 a +140 %) — es la zona de resonancia, donde la brecha de ~9 % en
frecuencia (E1) desplaza el pico. En el **tope** el 3D es el más fiel (modela el contacto) y en el
**rápido** las cuatro coinciden. θ (brazo) sigue mejor en todo el barrido. La media de amplitud se
reporta con la advertencia de que el % explota donde la amplitud real es mínima (resonancia): allí la
métrica robusta es el RMSE absoluto.

### 11.2 E3: métrica correcta por zona (el RMSE de α no vale en swing-up)

Durante el swing-up α salta ±180° en la vista **envuelta**, de modo que el RMSE punto a punto sobre la
señal envuelta es engañoso (72–90°). La solución correcta es calcular las métricas sobre α
**desenvuelta** (continua), que sí es comparable: el swing-up se juzga por sus **eventos** (captura y
vaivenes) y, además, con el RMSE de α desenvuelta por zona (la figura puede seguir mostrándose
envuelta, más legible). RMSE de α (desenvuelta, modelos vs real, deg):

| Zona | QSM=SIM | RTB | 3D |
|---|---|---|---|
| General | 11.4 | 10.2 | 19.1 |
| Swing-up | 24.9 | 22.3 | 41.7 |
| Transición | 6.3 | 4.5 | 7.0 |
| Balance | 0.27 | 0.19 | 0.14 |

Sobre un swing de ±180° con 7 vaivenes, un RMSE de 22–25° (QSM/RTB) es buen seguimiento; el 3D queda
peor (41.7°) porque captura antes (2.676 s). Nota sobre las barras de "RMSE vs real": no llevan barra
del real, porque el error se mide contra el real (real vs real = 0). Resumen por zona (figura
`E3_zonas.png`, 6 paneles):

| Zona | métrica | real (n=10) | QSM=SIM | RTB | 3D |
|---|---|---|---|---|---|
| Swing-up | captura [s] | 2.733±0.003 | 2.732 | 2.716 | 2.676 |
| Swing-up | vaivenes | 7 | 7 | 7 | 7 |
| Transición | asentam. 17°→3° [s] | 0.253±0.004 | 0.284 | 0.104 | 0.094 |
| Balance | RMS α [°] | 0.268±0.128 | 0.160 | 0.093 | 0.088 |
| Balance | dispersión θ [°] | 2.18 | 1.94 | 0.55 | 0.15 |
| Balance | RMSE α vs real [°] | — | 0.30 | 0.24 | 0.26 |

Lectura (que hay que dejar explícita en el texto): **α general es casi idéntico** entre modalidades
(swing-up de 7 vaivenes y captura común; la superposición general está en `E3_banda.png`); **por fases,
el swing-up y la transición coinciden**, y **solo el balance cambia**, porque ahí manda el ruido/la
fricción físicos: el real dispersa más (RMS α 0.27°, σ visible corrida a corrida) y los modelos
deterministas regulan más fino. Esa diferencia de balance es de la planta física, no del modelo.

### 11.3 ¿θ por fases? — recomendación

No es necesario para θ el desglose que sí requiere α. θ es continua (no tiene wrap), así que el punto a
punto vale en todo el registro; basta reportar θ **general** (RMSE ≈ 6.9°, muy buena) y su **dispersión
en balance** (std θ, ya incluida). El comportamiento de θ en swing-up ya se ve en la banda
(`E3_banda.png`). Un desglose por fases de θ añadiría poco.

### 11.4 Signos e inversiones (efecto en tablas)

Las inversiones detectadas (θ del 3D en E3; α de QSM y RTB en E3; plegado conjunto de α y θ en E1) son
de **convención de signo/dirección** y se corrigen alineando cada señal al real por correlación. **No
cambian** las métricas escalares de fidelidad (f_n, ζ, std, RMS, RMSE, captura, vaivenes son
invariantes al signo o se calculan tras alinear), de modo que **las tablas de resultados no cambian**
por este motivo; solo mejora la legibilidad de las figuras y se corrige la banda/media de θ en E1
(σ_θ ≈ 1.5°).

### 11.5 Respuesta a la hipótesis (Sección~\ref{sec:marco:hipotesis})

**Enunciado:** la ejecución en tiempo real modifica de forma medible la fidelidad del gemelo y ese
efecto se relaciona con el jitter y los overruns.

**Respuesta: la hipótesis se RECHAZA en su forma fuerte y se REDEFINE.** Evidencia:
1. Con el integrador fijo, **QSM (tiempo real, QUARC) y SIM (simulación convencional) dan la misma
   trayectoria** en los tres ensayos (E1 f_n 2.203 en ambos; E2 α/θ idénticas; E3 balance idéntico).
   Es decir, la ejecución en tiempo real **por sí misma no modifica la fidelidad**.
2. La única diferencia de trayectoria entre sustratos es **RTB (Euler) vs QSM/SIM (RK4)**, atribuible
   al **método de integración**, no al jitter ni a los overruns; de hecho **no hubo overruns** en el
   punto de operación y el jitter (µs) no altera un solver de paso fijo.
3. Por tanto, jitter y overruns gobiernan el **determinismo temporal** (Sección de RTS), no la
   fidelidad; la fidelidad la gobiernan el **modelo** (brecha ~9 % con el real) y, en segundo orden, el
   **integrador**.

Redacción sugerida (Discusión y Conclusiones): *«La hipótesis no se sostiene en su forma original: el
tiempo real no modifica de forma medible la fidelidad del gemelo (QSM ≡ SIM), sino su determinismo
temporal. La única diferencia de fidelidad entre sustratos proviene del método de integración
(Euler vs Runge–Kutta), no del jitter ni de los overruns. La hipótesis se redefine así:
el sustrato de tiempo real condiciona el determinismo temporal, mientras que la fidelidad depende del
modelo y del integrador, con independencia de la ejecución en tiempo real.»*

---

## 10b. Figuras de corridas individuales (n=5) y corrección del plegado de θ

Se añaden, por experimento, figuras que superponen **5 corridas reales** en α y θ (más su media),
para mostrar de dónde nace la dispersión y cómo varía cada ejecución:

- `E1_corridas.png`: en α las cinco corridas casi se solapan (muy repetible); en θ, tras el plegado
  correcto, se alinean y la variación principal es una corrida ligeramente más lenta.
- `E2_corridas.png`: θ es muy repetible entre corridas; α oscila alrededor del colgado y **diverge**
  entre corridas (por eso no es comparable punto a punto y se usa θ).
- `E3_corridas.png`: el swing-up es casi idéntico entre corridas; en el **zoom de balance** se ve la
  variación corrida a corrida — una corrida (la 4) queda sesgada en +0.5–1° (es la ruidosa, RMS
  0.58°), mientras las demás oscilan cerca de 0 con la cuantización del encoder (±0.5°). Esto explica
  visualmente el intervalo de confianza ancho del RMS de α en balance.

**Corrección aplicada (plegado de θ en E1).** Al plegar por dirección de caída en E1 (para agrupar las
corridas que caen a un lado y al otro) debe invertirse **α y θ juntas**; antes solo se invertía α, lo
que dejaba a las corridas 4 y 9 con θ en fase opuesta e inflaba artificialmente la banda de θ y
achataba su media. Con el plegado correcto, σ_θ de E1 baja a ≈1.5°. La figura `E1_banda.png` y el
`E1_stats.mat` ya están regenerados con esta corrección.

## 10. Archivos generados

Figuras (`figs/resultados/`): `E1_banda.png`, `E1_barras.png`, `E1_periodo_amplitud.png`,
`E1_corridas.png`, `E2_banda.png`, `E2_segmentos.png`, `E2_corridas.png`, `E3_banda.png`,
`E3_zonas.png`, `E3_corridas.png`, `E_alpha_wrap_unwrap.png`.
Datos: `E1_stats.mat`, `E1_fnz.mat`, `E2_seg.mat`, `E3_zonas.mat`, `E3_modzonas.mat`.
Script: `analisis_bandas_tesis.m` (regenera todo; verificado).

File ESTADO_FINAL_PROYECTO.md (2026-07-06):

# Estado final del proyecto — Gemelo digital del péndulo de Furuta (QUBE-Servo 3)

Documento maestro de estado. Consolida hasta dónde está el trabajo y qué queda. Actualizado tras
cerrar los capítulos de la tesis y la integración de las modalidades de tiempo real en el
repositorio. **Único pendiente operativo: subir el repositorio** (el pulido de cierre del
repositorio está completo).

## Resumen de una línea

El gemelo digital analítico (M1) del péndulo de Furuta se construyó, se validó contra el modelo 3D
(M2) y contra el equipo real (M0), se le cerró el lazo con un observador (EKF de estado aumentado) y
un banco de control (swing-up por energía + balance LQI), y se desplegó sin cambios sobre cuatro
sustratos de ejecución (SIM, QSM, QHW, RTB) para medir la influencia de la simulación en tiempo real
sobre la fidelidad, la sincronización y el desempeño. Todo el material de respaldo está en este
repositorio.

## Qué está terminado

1. **Modelo 3D (M2) y parámetros.** SolidWorks → Simscape Multibody; dimensiones medidas y masas
   pesadas; parámetros físicos identificados por ensayo aislado y consolidados en
   `codigo/parametros_furuta.m` (g=9.7807, Ts=0.002). Cable del encoder: dinámica simplificada
   (rigidez, fricción seca, amortiguamiento de primer orden); la no linealidad de enrollamiento queda
   documentada como limitación.
2. **Modelo analítico (M1).** Euler-Lagrange, `f(x,u)` y jacobianos en forma cerrada; reproduce al 3D
   (RMSE θ=0.64°, α=0.83°); polo inestable en +13.42 rad/s.
3. **Observador (EKF).** Estado aumentado con la perturbación del cable; R=q²/12=7.84e-7,
   Q=diag(1e-7,1e-7,1e-5,1e-5,1e-4); sintonía por NIS; funciones codegen para Simulink; UKF ensayado
   y descartado.
4. **Control.** Banco swing-up + balance (LQI/LQR/PD/PID/LQG) sobre el estado estimado; conmutación en
   |α|≲17°; compensación por adelanto de la perturbación del cable.
5. **Gemelo bidireccional.** Acoplamiento físico-virtual por el propio EKF; espejo 3D con
   sincronizador; verificación de construcción en paralelo (real vs 3D, sin sincronización).
6. **Modalidades de ejecución (RTS).** Mismo M1 sobre simulación convencional (SIM), kernel de tiempo
   real de QUARC sobre el modelo (QSM), QUARC sobre la planta real (QHW = M0) y RT Box de PLECS (RTB),
   en los tres ensayos E1 (caída libre), E2 (respuesta forzada) y E3 (lazo cerrado). Comparación de
   fidelidad y de métricas de tiempo real completa.
7. **Hallazgos documentados.** Piso de 1 ms del temporizador de software de QUARC en Windows;
   sensibilidad del conteo de vaivenes del swing-up al integrador (Euler en RTB vs RK4 en QUARC) y a
   la idealización del modelo; dificultad intrínseca del sistema subactuado/inestable.
8. **Tesis (LaTeX).** Capítulos terminados y revisados: Marco Teórico (con las ecuaciones del EKF,
   LQR/LQI y el modelo analítico completo), Metodología, Desarrollo, Resultados, Conclusiones y
   recomendaciones, Resumen y Abstract. Figuras y tablas ajustadas. Fuente en
   `Documento/TESIS/` (fuera de este repositorio de código/datos).

## Estado del repositorio (TESIS_FINALES)

~305 archivos versionados (excluye artefactos de build), organizados por tema. Cierra el ciclo completo del trabajo:

```
TESIS_FINALES/
├── codigo/            (47)  parametros_furuta.m + referencia/ identificacion/ validacion/ modelo_control/ gemelo/
├── datos/             (38)  por tema (identificación, calibración, control, gemelo, validación)
├── figuras/           (46)  por tema (modelo_3d, motor, cable, contacto, alpha, analítico, ekf, control, gemelo, validación)
├── modelos/           (33)  .slx por tema (modelo_3d, ekf_control, gemelo, identificación, validación)
├── RTS_modalidades/  (133)  SIM/ QSM/ QHW/ RTB/ comparacion/ scripts/ docs/ (las 4 modalidades + comparación)
├── README.md                  (portada del repositorio)
├── ESTADO_FINAL_PROYECTO.md   (este archivo)
├── INDICE_documentacion.md    (índice unificado de la documentación)
└── LICENSE, CITATION.cff       (licencia MIT y cómo citar)
```

Una auditoría de completitud confirmó 0 figuras citadas faltantes y el código al día; `RTS_modalidades/`
incorpora la etapa de modalidades de tiempo real.

## Estado del cierre (completado)

El alistamiento del repositorio se completó en cinco fases:

- **Fase 1** — verificación funcional de los `.m` dentro de la estructura de subcarpetas.
- **Fase 2** — arranque automático (`PreLoadFcn`/`InitFcn`) en los modelos `.slx`.
- **Fase 3** — comentarios y encabezados a estilo técnico impersonal (sin cambios de lógica).
- **Fase 4** — `.gitignore`, unificación de nombres de figuras y depuración de duplicados.
- **Fase 5** — `LICENSE` (MIT), `CITATION.cff`, `README.md` por carpeta y verificación del índice.

En el cierre se corrigió además `parametros_furuta.m` (`Ts` 0.004 → 0.002, coherente con el resto
del repositorio) y un defecto de filtrado en `Analisis_pendulo_oscilacion_libre.m`.

El repositorio contiene ~305 archivos versionados (los artefactos de build quedan excluidos por
`.gitignore`). **Único pendiente: `git init` + commit y subida a GitHub**, desde una terminal local.

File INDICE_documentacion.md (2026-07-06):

# Índice unificado de la documentación

Punto de entrada único a toda la documentación del proyecto. Reúne (une) los documentos dispersos que
se produjeron durante el trabajo, agrupados por tema. Las rutas relativas parten de `Scape/`.

Convención: **[GD]** = carpeta `Gemelo Digital del pendulo invertido de Furuta usando el QubeServo 3
de Quanser/` (documentos de proceso). **[RF]** = `TESIS_FINALES/RTS_modalidades/docs/`. **[TF]** =
`TESIS_FINALES/`.

## 0. Estado y navegación
- **[TF] ESTADO_FINAL_PROYECTO.md** — estado global; qué está hecho y qué queda.
- **[TF] README.md** — portada del repositorio, estructura y guía de uso.
- **[TF] LICENSE**, **[TF] CITATION.cff** — licencia MIT y forma de citar.
- **[TF] codigo/README.md · datos/README.md · figuras/README.md · modelos/README.md** — índice por carpeta.
- **[GD] INVENTARIO_archivos_finales_tesis.md** — inventario de archivos por sección de la tesis.
- **[GD] AUDITORIA_documentacion_vs_tesis.md** — cruce documentación ↔ capítulos.

## 1. Modelado 3D y parámetros
- **[GD] modelos_v4_y_Model3d_legible.md** — modelo 3D (SolidWorks→Simscape) legible.
- **Scape/DOCUMENTACION_Ensamblaje_pendulo_furuta_multibody_v4.md** — ensamblaje multibody v4.
- **[GD] metodologia_gemelo_digital.md** — metodología general de construcción del gemelo.

## 2. Identificación de parámetros (§4.3)
- **[GD] metodologia_cable_encoder_theta.md** — cable del encoder sobre θ (rigidez, fricción, tope).
- **[GD] calibracion_protocolo.md** — protocolo de calibración por excitación aislada.
- **[GD] analisis_paper_Le2020_cable_y_motor.md** — parámetros de motor y cable desde Le et al. (2020).
- **[GD] instrucciones_linealizacion_simscape.md** — linealización del 3D (cross-check de polos).

## 3. Modelo analítico y observador (§4.4–§4.5)
- **[GD] modelo_alta_fidelidad_observador.md** — modelo analítico + EKF de alta fidelidad.
- **[GD] implementacion_gemelo_en_linea.md** — implementación en línea del observador/control.

## 4. Control, swing-up y gemelo bidireccional (§4.6–§4.8)
- **[GD] etapa5_construccion_paso_a_paso.md** — construcción incremental (EKF→control→banco).
- **[GD] guia_E3_swingup_hibrido.md** — swing-up por energía + conmutación a balance.
- **[GD] acoplamiento_bidireccional_real_digital.md** — acoplamiento físico-virtual (bidireccional).
- **[GD] guia_dashboard_gemelo.md** — visualización/dashboard del gemelo.

## 5. C-Scripts (RT Box / PLECS)
- **[GD] guia_cscripts_plecs.md** — guía completa de los C-Scripts en PLECS.
- **[GD] cscript_PLANTA_corregido.md**, **cscript_control_ekf_swingup.md**, **cscript_excitacion_E2.md**
  — transcripción y notas de cada C-Script.
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

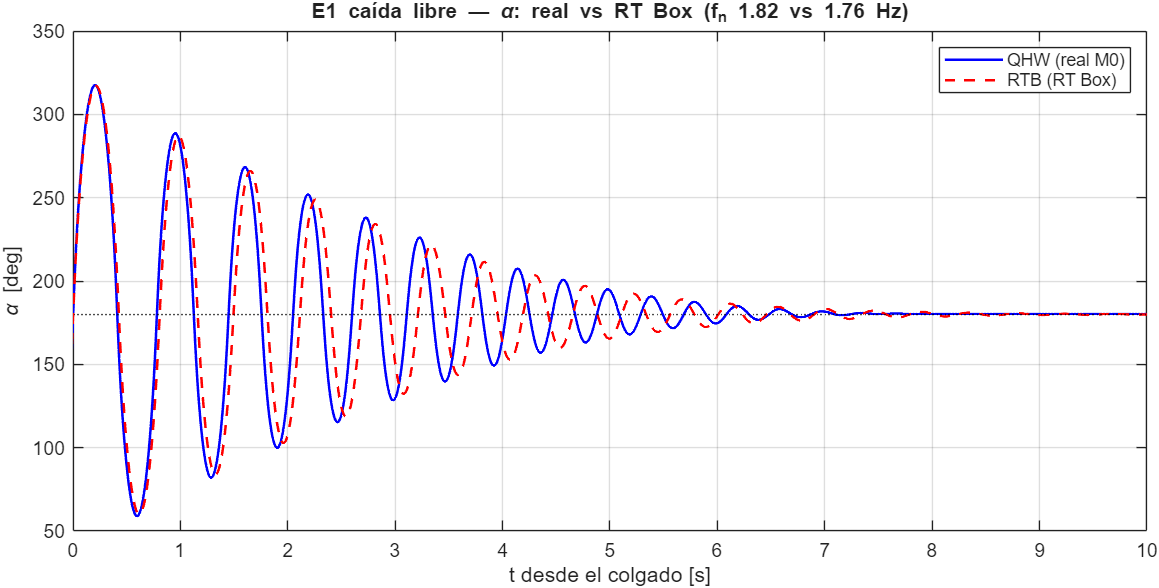
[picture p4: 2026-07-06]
RTS_modalidades/RTB/overlay_E1_qhw_vs_rtbox.png

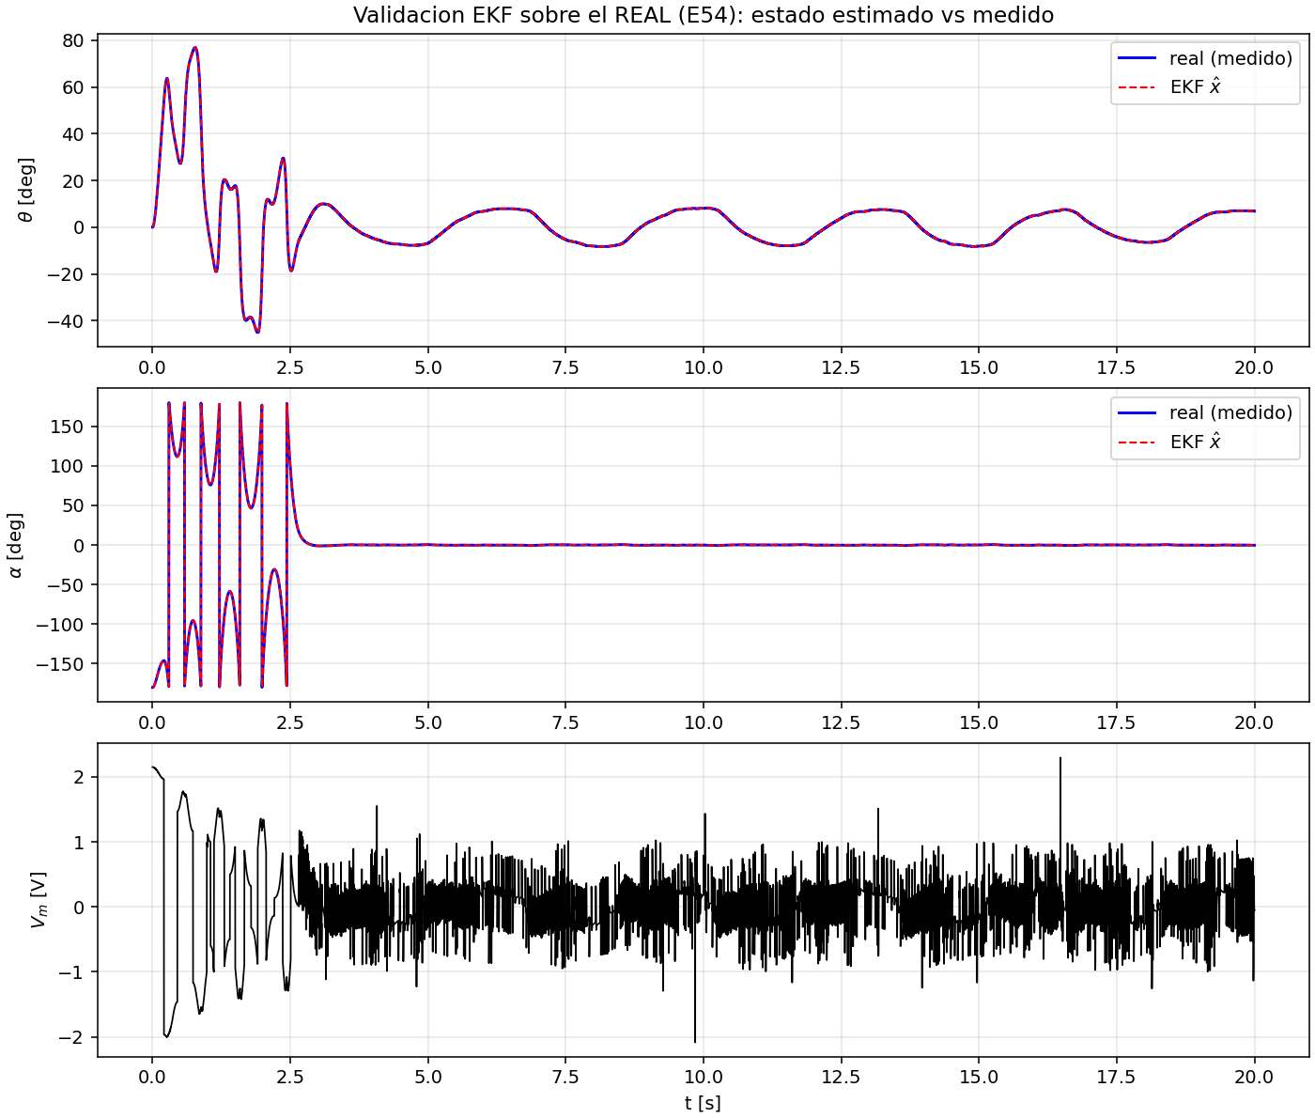
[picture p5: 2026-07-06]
figuras/ekf/ekf_vs_real_E54.png

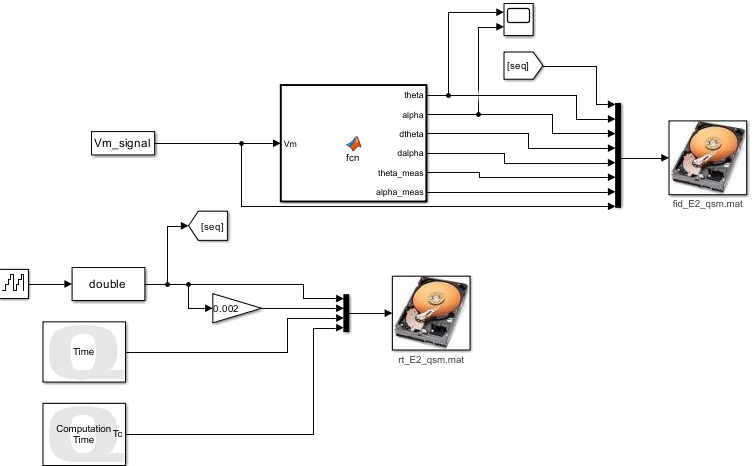
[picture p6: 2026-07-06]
RTS_modalidades/QSM/E2_QSM_SIMULINK.png

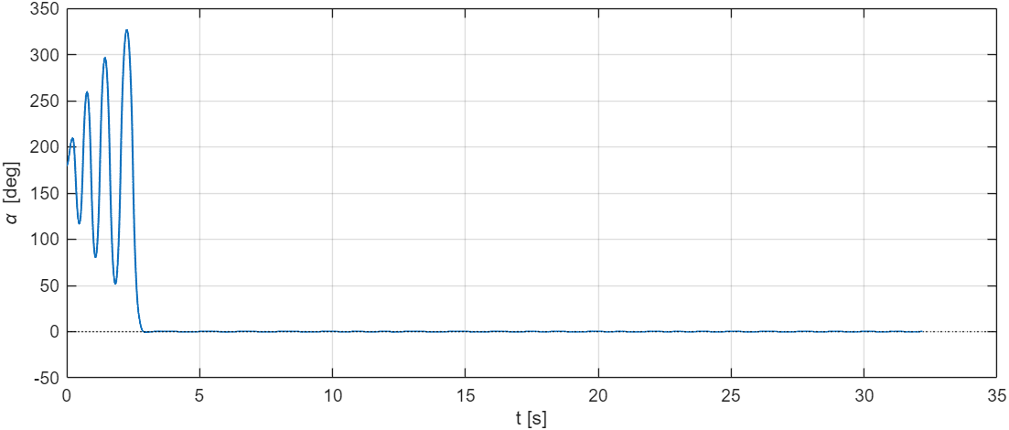
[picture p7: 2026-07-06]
RTS_modalidades/RTB/E3_rtbox_alpha.png

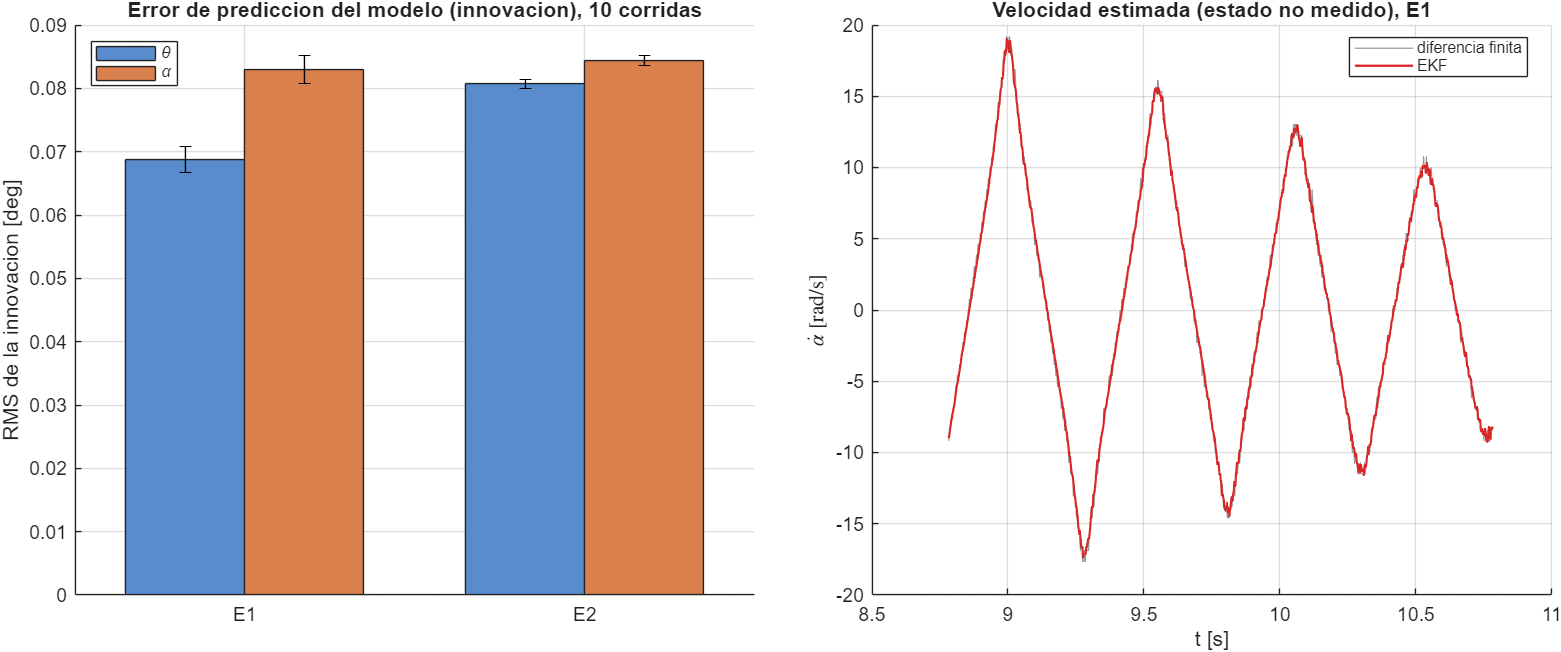
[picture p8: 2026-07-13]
figuras/validacion/EKF_innov.png

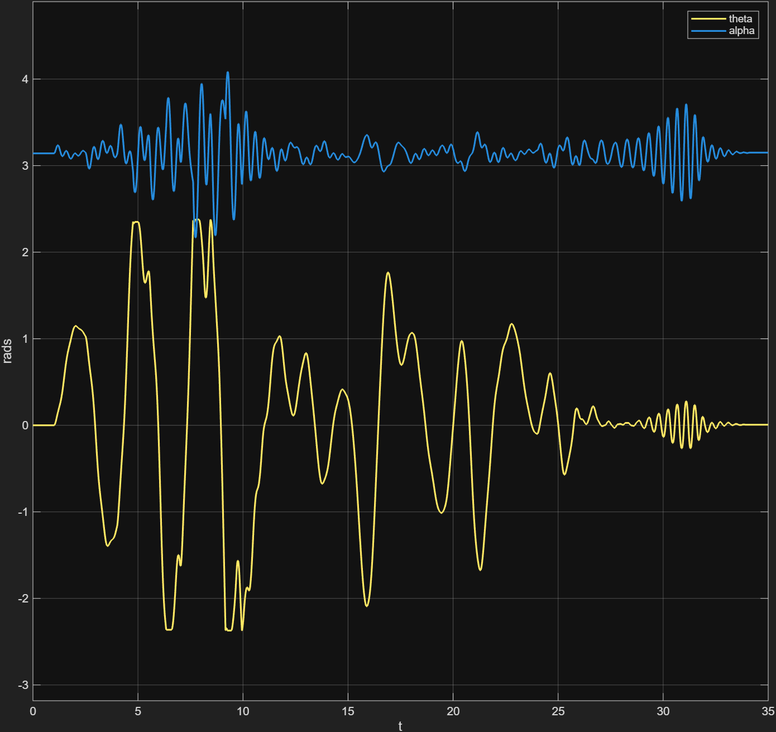
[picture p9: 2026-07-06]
RTS_modalidades/QHW/E2_scope_theta_alpha.png

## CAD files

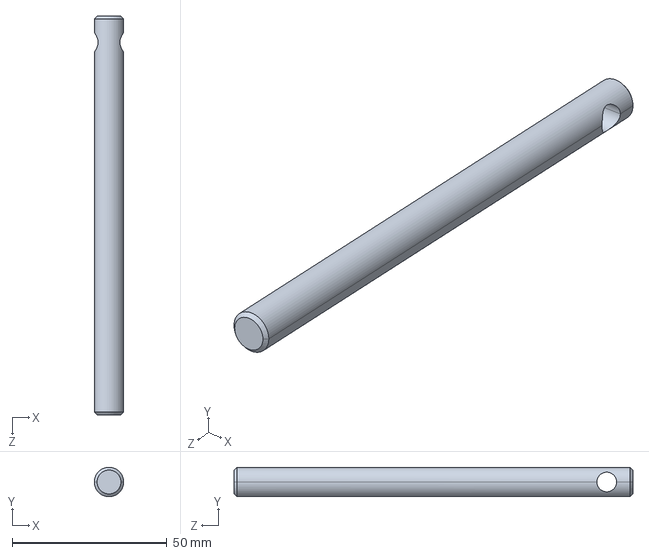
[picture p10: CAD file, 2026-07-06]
modelos/modelo_3d/Sólido4_Predeterminado_sldprt.STEP
9.50 x 9.50 x 129.0 mm

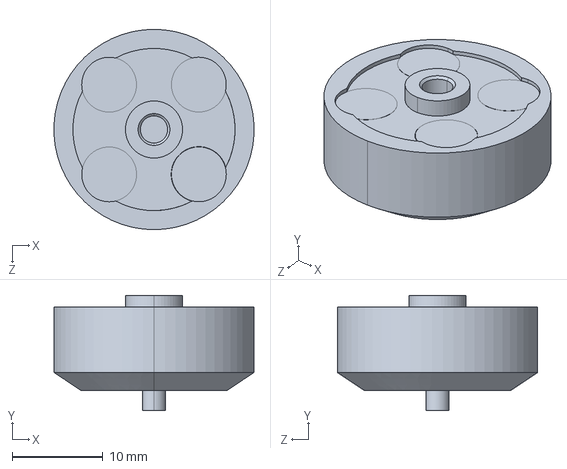
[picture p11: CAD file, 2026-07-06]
modelos/modelo_3d/disco_hub_Predeterminado_sldprt.STEP
22.1 x 12.7 x 22.1 mm

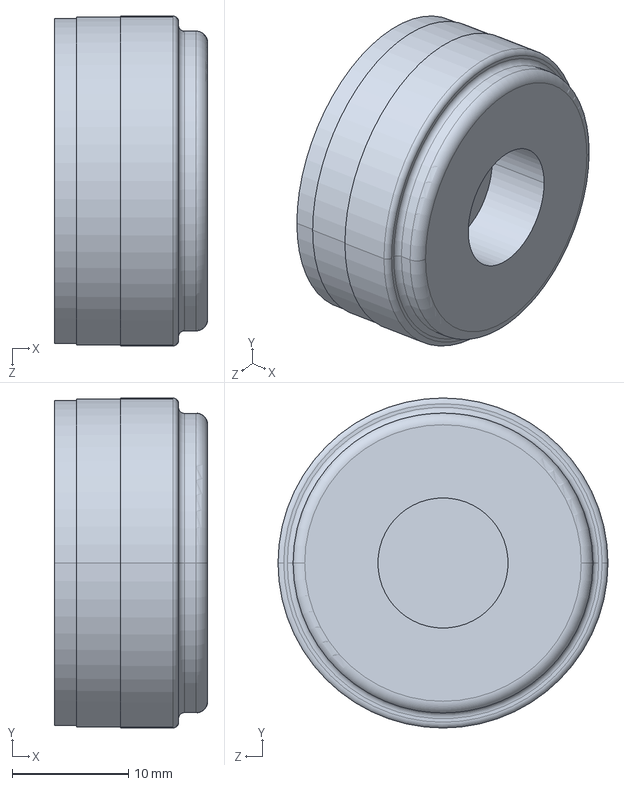
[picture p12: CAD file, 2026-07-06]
modelos/modelo_3d/Plastico_enc_Predeterminado_sldprt.STEP
13.2 x 28.4 x 28.4 mm

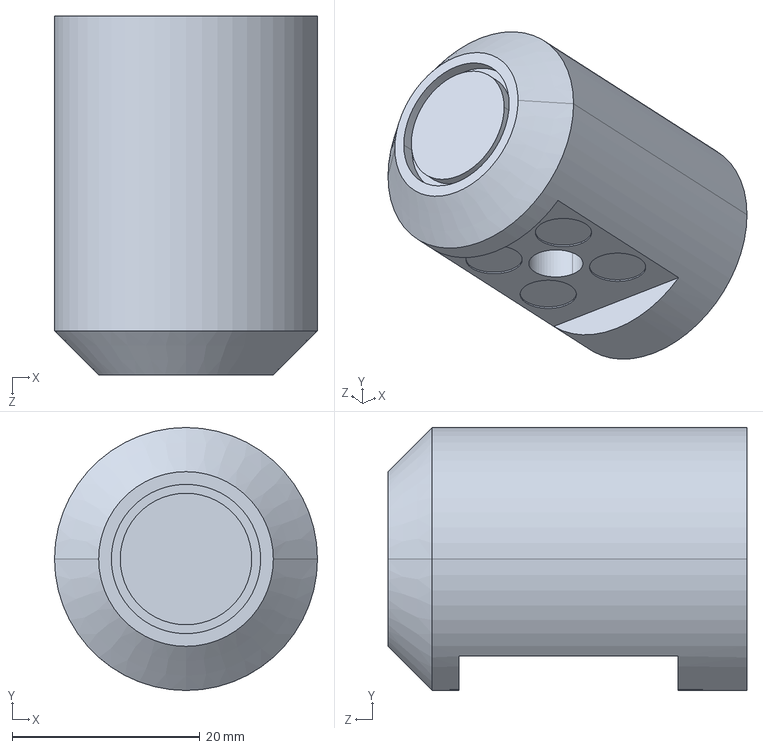
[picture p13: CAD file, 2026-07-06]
modelos/modelo_3d/Sólido1_Predeterminado_sldprt.STEP
28.0 x 28.0 x 38.2 mm

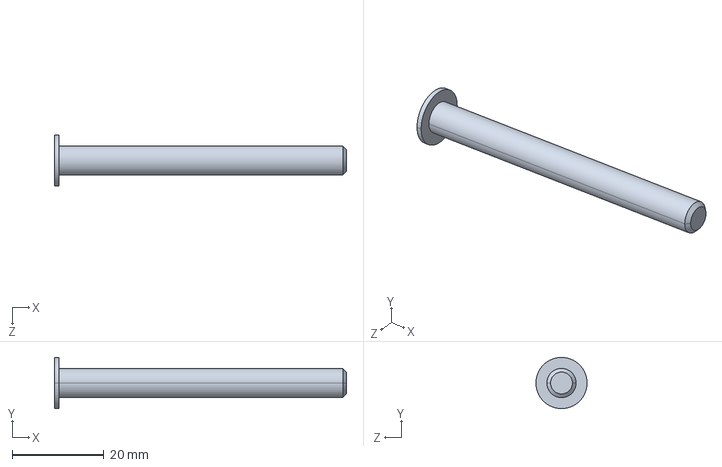
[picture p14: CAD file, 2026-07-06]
modelos/modelo_3d/Sólido3_Predeterminado_sldprt.STEP
63.5 x 11.2 x 11.2 mm

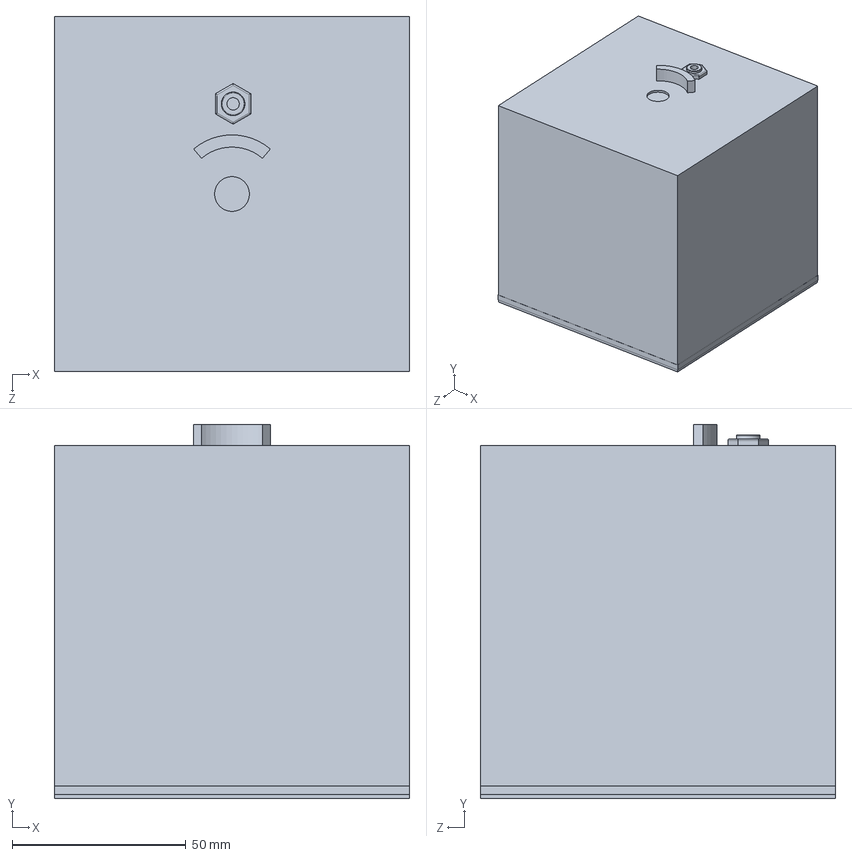
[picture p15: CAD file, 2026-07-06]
modelos/modelo_3d/base_qube_Predeterminado_sldprt.STEP
102.2 x 107.6 x 102.2 mm

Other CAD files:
modelos/modelo_3d/pendulo_r_Predeterminado_sldprt.STEP
modelos/modelo_3d/Sólido2_Predeterminado_sldprt.STEP
modelos/modelo_3d/Cilindro_enc_Predeterminado_sldprt.STEP
modelos/modelo_3d/brazo_Predeterminado_sldprt.STEP

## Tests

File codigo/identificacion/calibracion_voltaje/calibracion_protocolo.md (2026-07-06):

# Protocolo de calibración del modelo (alta fidelidad) — Furuta QUBE-Servo 3

Define cómo calibrar correctamente los parámetros físicos del modelo contra el real, como paso previo al gemelo de alta fidelidad. Citas `[n]` según `fuentes_bibliograficas_proyecto.md`.

## 0. Principios (por qué así y no de otra forma)

- **Excitación aislada por parámetro.** Cada parámetro se identifica con un experimento que **excita ese efecto** y silencia los demás. Calibrar "todo a la vez" desde una corrida de **balanceo** es **inválido**: en balanceo θ y θ̇ casi no se mueven → la rigidez del cable y la fricción **no se excitan** (regresor mal condicionado). *Evidencia:* `calibrar_modelo.m` sobre 4 balanceos explicó solo **7%** de `d̂` y dio `kc` 290× el real.
- **Medir, no inferir desde `d̂`.** La perturbación `d̂` del EKF es un **cajón de sastre** (absorbe estructura no modelada y escalados): no es un par físico limpio (sale ~0,15 N·m, 65× el par del motor). No sirve como señal de calibración. Se mide el par real (vía `τ=kt·Vm/Rm`) o se observa la dinámica libre.
- **Validar en datos independientes** [13]: los parámetros se identifican en unas corridas y se **validan en otra distinta** (error de predicción a horizonte corto, no en la misma data del ajuste).
- **Parsimonia** [13]: el modelo ya tiene la estructura (cable resorte, Coulomb+viscoso por junta, motor). Calibrar = afinar esos coeficientes, no añadir términos.

## 1. Cable del encoder en θ: rigidez `kc` y reposo `θ0` (+ fricción seca del brazo)

- **Excita:** posición del brazo θ. **Silencia:** velocidad/inercia (cuasi-estático) y el péndulo (déjalo colgando fijo o retíralo).
- **Procedimiento:** mueve el brazo θ **muy lento** (triángulo, θ̇≈0) por su rango, en ambos sentidos; loguea `Vm` y `θ`. Par aplicado `τ ≈ kt·Vm/Rm` (a θ̇≈0 no hay viscoso ni inercia).
- **Extrae:** grafica `τ` vs `θ` → es un **lazo de histéresis**. La **pendiente** = `kc`; la **media-altura** del lazo = `Tdry_th` (fricción seca total del brazo); el centro = `θ0`.
- **Estado:** YA HECHO (`identificacion_cable_theta.m`, 3 corridas v2 → `kc=1,19e-3`, `Tdry_th=0,71e-3`). Refinar solo si la validación (§6) lo pide. Ref. del cable de este encoder [9].

## 2. Fricción del brazo: viscoso `Dr` y Coulomb `Tdry_th` (confirmación)

- **Excita:** velocidad del brazo θ̇. **Silencia:** el péndulo (colgando/retirado) y la transitoria (régimen permanente).
- **Procedimiento:** lleva el brazo a **velocidad constante** a varios valores (lazo abierto con `Vm` constante, espera el régimen), loguea `Vm`, `θ̇`. Par mecánico `τ_mec = kt·Vm/Rm − km·θ̇` (resta la fcem). Resta también el cable `kc·(θ−θ0)`.
- **Extrae:** `τ_mec` vs `θ̇` → recta por tramos: **ordenada** = `Tdry_th` (Coulomb), **pendiente** = `Dr` (viscoso). Modelo de fricción seca+viscosa [10]; flujo tipo barrido par–velocidad [16]; mapeo a los 4 parámetros del bloque Simscape *Rotational Friction* [20].

## 3. Amortiguamiento del péndulo: Coulomb `Tc_alpha` y viscoso `Dp`

- **Excita:** oscilación libre del péndulo. **Silencia:** el motor (apagado) y el brazo (bloqueado).
- **Procedimiento:** con el motor off y el brazo fijo, desplaza el péndulo y **déjalo oscilar libre**; loguea `α`.
- **Extrae:** el **decaimiento** de la envolvente: caída **lineal** ⇒ Coulomb (`Tc_alpha`), caída **exponencial** ⇒ viscoso (`Dp`) (decremento logarítmico). En el Furuta la fricción de α es dominada por Coulomb y pequeña [12] (`Tc_alpha~6,1e-6`, `Dp≈0`).

## 4. Inercias

- **`Jp` (péndulo):** de la geometría (`mp`, `Lp` medidos) → `Jp_cm=(1/12)mp Lp²`. Confiable, no calibrar.
- **`Jr` (brazo+rotor):** dos vías cruzadas — (a) del **CAD** (`Jr_desde_CAD.m` → 1,38e-4); (b) con `kc` conocido, el brazo (péndulo retirado) es un **oscilador torsional** de `ωn=√(kc/Jr)` → mide su frecuencia natural → `Jr=kc/ωn²`. Que ambas coincidan valida `Jr`.

## 5. Motor DC (`Rm`, `kt`, `km`)

- Del **manual** (Tabla 2.2) [15]; `km=kt`. Verificación opcional: ensayo de par/corriente en bloqueo. Su **fricción mecánica** ya está incluida en `Tdry_th` (§1–2), **no** sumarla aparte.

## 6. Validación (el paso que faltaba)

- Haz **una corrida independiente RICA EN EXCITACIÓN** (no usada en la identificación): mueve la referencia de θ con un **chirp/escalones/PRBS** (péndulo colgando o retirado), loguea `Vm`, `θ`, `α`.
- **Métrica:** alimenta el modelo (analítico o Simscape) con el `Vm` logueado y compara su salida con la medida → **error de predicción** a horizonte corto (1–N pasos). Con buenos parámetros, el error de predicción baja y el `d̂` del EKF en esa corrida se reduce respecto a los valores actuales.
- Es la validación cruzada de Ljung [13]: identificar en unas corridas, validar en otra.

## 7. Dónde se aplica la calibración

1. `parametros_furuta.m`: `p.kc`, `p.theta0`, `p.Tdry_th`, `p.Dr`, `p.Tc_alpha`, `p.Dp`, `p.Jr`.
2. **Re-correr `derivar_modelo_furuta_EKF.m`** → re-hornea `furuta_f_aug`/`furuta_Fc` con los nuevos valores.
3. **Modelo 3D/Simscape:** poner los MISMOS valores en el bloque *Rotational Friction* del brazo (Coulomb=`Tdry_th`, viscoso=`Dr`) y del péndulo (`Tc_alpha`), y en el resorte del cable (`kc`, `θ0`). Así la planta digital y el modelo del observador comparten física.

## 8. Alternativa: identificación conjunta automática

Si en vez de tests aislados quieres un ajuste conjunto sobre una corrida rica en excitación:
- **Simulink Design Optimization → Parameter Estimation** sobre el modelo Simscape (parámetros como variables), o **System Identification → grey-box** (`idnlgrey`/`nlgreyest`). Optimizan todos los parámetros para minimizar el error entrada-salida. Requiere excitación persistente y buena identificabilidad; más potente pero con riesgo de mínimos locales. Recomendado solo para **refinar** tras la identificación aislada (§1–5), no para sustituirla.

## Resumen operativo

Lo que ya tienes (cable `kc`, fricción seca) viene de identificación aislada correcta — probablemente ya es bueno. Lo que **falta** para "calibración válida" es: (a) confirmar `Dr`/`Tc_alpha`/`Jr` con sus tests si hace dudar la validación, y sobre todo (b) **la corrida de excitación de validación (§6)** que mide objetivamente la fidelidad del modelo calibrado contra el real. Sin esa validación, no hay "calibración comprobada".

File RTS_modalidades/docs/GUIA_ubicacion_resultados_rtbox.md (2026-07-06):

# Guía de ubicación de resultados — modalidad RT Box (E1/E2/E3)

Indica qué se extrajo de la RT Box, qué gráfica va dónde (Desarrollo / Resultados) y con qué
consideraciones de redacción. Es el molde; las secciones de QUARC-modelo (QSM), QUARC-real (QHW) y
sim normal (SIM) se agregan igual. Post-proceso reproducible en `procesar_rtbox.m` (esta carpeta);
métricas en `metricas_rtbox.mat`. Comparativa cruzada en
`SIM_QUARC_RTS/postproceso_comparaciones/crosscheck_rtbox.m`.

> **Estado (corregido):** el pipeline reconstruye el tiempo como **seq × 2 ms** (tiempo-modelo), no
> desde el wall-clock. Con esto la box coincide con QSM y con el real en las tres pruebas (ver
> DIAGNÓSTICO, reescrito). El detalle del procedimiento de corrección está en
> `memo_correccion_2ms_RTBOX.md`.

## Reglas de redacción para TODAS las gráficas (aplican a las cuatro modalidades)
- **Un solo plot** → SIN título (el *caption* de la figura en LaTeX será el título; no redundar).
- **Varios subplots** → cada subplot con su título corto, SIN título general del conjunto.
- **Convención de α en lazo cerrado (E3):** graficar α de modo que **el último vaivén antes de la
  captura venga del lado POSITIVO** y luego balancee, para que coincida con el real (puede requerir un
  `×(−1)`). `procesar_rtbox.m` lo hace con `fix_alpha_convention`. Mismo criterio en QSM/QHW/SIM.
- Fondo blanco, `exportgraphics` a 140 dpi, ejes en grados para θ/α.

## Consideración de captura de RTS (para nombrar bien en Metodología/Resultados)
- **Tiempo-modelo (eje temporal):** la box loguea **una muestra cada 2 ms de MODELO**
  (`subTaskPeriod[0]=4 × paso base 0.5 ms`), confirmado en el `.c` generado (`tesis_E*_RTBOX.c`). El
  tiempo se reconstruye como **seq × 0.002 s**, NO desde el reloj de pared. (El `t_model` del `To File`
  puede omitirse; el eje bueno es `seq × 2 ms`.)
- **RTF (hallazgo de RTS aparte):** el wall-clock avanza ~1 ms por muestra mientras el modelo avanza
  2 ms → **RTF = modelo/pared ≈ 2.00** (exacto en E1, E2 y E3). La box **no sostuvo tiempo real 1:1**:
  ejecutó cada paso de 2 ms de modelo en ~1 ms de pared. Es un resultado de RTS (no afecta la
  fidelidad, que se integra en tiempo-modelo). Este "~1 ms por muestra" es el que antes se confundía
  con "la box loguea a 1 ms" y producía el factor 2 fantasma.
- **TET/overruns:** NO son señal del modelo en la RT Box (no hay bloque de TET en el target). Se
  obtuvieron por la **interfaz web / API JSON-RPC** con `rtbox_watch.py` (`queryCounter` + Application
  Log), volcados a `rts_sweep_*.csv` y `rt_E*_<paso>.txt/_cycle.csv`. El jitter de la box es ~0
  (hardware-locked).
- **QUARC (QSM/QHW):** el TET sí es señal (bloque *Computation Time*), el wall-clock viene de *System
  Time* y el RTF por `tic/toc` en sim normal. (Detalle en la doc maestra Simulink/QUARC.)

---

## Qué se extrajo por experimento (RT Box, tiempo-modelo 2 ms)

### E1 — caída libre (lazo abierto)
- **Fidelidad:** `f_n = 1.76 Hz`, `ζ = 0.053` del decaimiento de α (decremento logarítmico), reposo
  α = π. Coincide con QSM (1.72 Hz, ζ 0.057) y con el real M0 (QHW 1.82 Hz) dentro de la brecha M1↔M0
  (~3 %). Nota: `f_n` es dependiente de amplitud (péndulo no lineal); medir en el mismo régimen en las
  cuatro modalidades (el pipeline usa la cola de pequeña amplitud). El antiguo "hallazgo a reconciliar"
  del amortiguamiento (Dp=0) queda **resuelto**: box y QSM usan la misma M1 y dan la misma ζ.
- **Gráfica:** `E1_rtbox_senales.png` (subplots α, θ) → **Resultados** (fidelidad E1) o Desarrollo si se
  ilustra el montaje.

### E2 — respuesta forzada (lazo abierto)
- **Fidelidad:** θ topa en ±135° (max 136.1°), α en [113.4°, 237.1°] (≈ ±60° del colgado), Vm_max 1.5 V,
  con la excitación arrancando en **t = 1.0 s** (C-Script EXCITACION con `RATIO = 1`, un índice por
  muestra de 2 ms). Coincide con QSM (α [123.6, 225.1]°) y con el real (α [124.1, 234.1]°).
  ⚠ Usar la corrida **`fid_E2_rtbox.mat` con `RATIO = 1` y PLANTA de parámetros vigentes** (α ∈ ~[113,
  237]°). Corridas intermedias con `RATIO = 2` (excitación estirada 2×, arranca en t = 2.0 s) o con la
  PLANTA de inercia vieja (α que se dispara a ~[3, 317]°) **NO son válidas** — ver el memo.
- **Gráfica:** `E2_rtbox_senales.png` (subplots θ, α, Vm) → **Resultados** (fidelidad E2, respuesta a la
  excitación; útil para el overlay contra el real).

### E3 — lazo cerrado (swing-up + balance + EKF)
- **Fidelidad/desempeño:** captura en **t = 2.72 s**, balance **91.6 %** del tiempo, α_std balance
  **0.60°**, θ_std **0.69°**, NIS medio **1.10** (consistente), `∫Vm²dt` **9.91**, E_max **30.2 mJ**
  (=Er). Coincide con QSM (catch 3.13 s, bal 79 %, α_std 1.11°, NIS 1.50) y con el real (catch 2.65 s,
  bal 82 %, α_std 1.12°, NIS 1.52): QSM ≈ QHW casi exacto; la box balancea algo más apretado (sustrato
  bare-metal). El swing-up sube la energía de 0 a Er en las tres.
- **Gráficas:** `E3_rtbox_senales.png` (subplots α, θ, Vm, E&mode; α con convención corregida) →
  **Resultados** (desempeño del lazo cerrado); `E3_rtbox_alpha.png` (α sola, un solo plot, SIN título) →
  figura de la captura/balance con caption.

### RTS — barridos de paso base
- **Lazo abierto (E1/E2):** TET_max ≈ 6.7–7.8 µs (casi constante), umbral de overrun ≈ **5 µs**
  (5120 overruns), carga 150 % a 5 µs. Fuente `rts_sweep_openloop_E2.csv`.
- **Lazo cerrado (E3):** TET_max ≈ 16–17 µs (el EKF ~triplica el TET), umbral ≈ **10 µs**
  (10240 overruns). Fuente `rts_sweep_closedloop_E3.csv`.
- Los barridos son **independientes de la parametrización del péndulo y del eje temporal** (miden costo
  de cómputo) → no se re-corren; siguen válidos tal cual.
- **Gráficas:** `rtbox_barrido_openloop.png`, `rtbox_barrido_closedloop.png` (subplots TET vs paso, y
  carga/overruns vs paso) → **Resultados** (capítulo RTS, tabla + figura del headroom de la box).

---

## Dónde va cada cosa (Desarrollo vs Resultados)

**Última parte del Desarrollo — "Implementación de las modalidades":** el *montaje* de cada modalidad
(no los datos): esquemático PLECS (`E*_PLECS.png`), C-Scripts PLANTA/CONTROL/EXCITACION, despliegue en
la RT Box, mismo Ts = 2 ms, cómo se capturó el TET/overruns (web/API + `rtbox_watch.py`). Aquí va la
corrección del texto actual (que decía "RT Box pendiente" y que QUARC usa "timer de hardware" — en win64
QUARC usa el **timer de software** de Windows). Las capturas de bloques/scopes ilustran el montaje.

**Resultados — capítulo de comparación de modalidades:**
1. **Fidelidad** por experimento (E1 `f_n`/ζ; E2 respuesta; E3 índices de swing-up/balance/NIS), con las
   gráficas de señales y, cuando corresponda, el overlay contra el real (M0).
2. **RTS** por sustrato: tabla y figuras del barrido (box abierto/cerrado), TET/overruns/jitter, RTF, y
   el contraste *compute-bound* (box) vs *timer/jitter-bound* (QUARC) del hallazgo del timer. Incluir el
   **RTF ≈ 2 de la box** (no sostuvo 1:1) como observación de RTS.
3. **Comparación cruzada** de las cuatro modalidades contra M0 (RMSE θ/α alineado por τ*, etc.).

**Resultados — parte cualitativa aparte de las modalidades:** además de las modalidades, van resultados
**cualitativos** de α/θ del modelamiento y la **comparación en paralelo**: (a) lazo cerrado con la
**planta real** + EKF + control, y (b) el mismo esquema con el **modelo 3D** en vez de la planta real. En
Desarrollo esto fue cuantitativo; en Resultados va cualitativo. Fuentes en `TESIS_FINALES/` y
`datos/gemelo/`.

## Estado de la comparación cruzada (siguiente paso)
- [x] Amortiguamiento/parametrización de α de la box reconciliado: **box ≡ QSM ≡ real** (misma M1),
  confirmado en E1 (`f_n`/ζ), E2 (rangos) y E3 (índices). Ya no hay que regenerar el C-Script PLANTA.
- [x] Mismo `procesar_*` aplicado a la box; `crosscheck_rtbox.m` aplica la misma medición de `f_n`/ζ
  (mismo régimen) y la misma convención de α a QSM/QHW/SIM.
- [ ] Tabla final de Resultados (fidelidad cruzada vs M0 + RTS de las 4 modalidades) — redacción.

---

## DIAGNÓSTICO (comparación box vs QSM vs real) — RESUELTO

**La RT Box NUNCA estuvo "2× off".** El síntoma (α de la box al doble de frecuencia y con más
amortiguamiento) era un **error de eje temporal**: el post-proceso reconstruía el tiempo desde el
wall-clock (~1 ms/muestra) cuando el `To File` loguea a **2 ms de modelo** por muestra
(`subTaskPeriod[0]=4 × 0.5 ms`, confirmado en el `.c` generado). Con el tiempo bien reconstruido
(`seq × 2 ms`), la box coincide con QSM y con el real:

| | f_α (E1) | ratio vs real |
|---|---|---|
| REAL (QHW, M0) | 1.82 Hz | — |
| **QSM** (`furuta_planta_analitica`) | 1.72 Hz | 0.95 ✓ |
| **RT Box** (M1 C-Script, seq×2 ms) | **1.76 Hz** | **0.97 ✓ coincide** |

Confirmación en las tres pruebas (`crosscheck_rtbox.m`):
- **E1:** f_n 1.76 (box) ≈ 1.72 (QSM) ≈ 1.82 (real) Hz; ζ 0.053 (box) ≈ 0.057 (QSM).
- **E2:** α ∈ [113, 237]° (box) ≈ [124, 225]° (QSM) ≈ [124, 234]° (real); θ topa ±136° y Vm_max 1.5 V en
  las tres.
- **E3:** balance firme en las tres, QSM ≈ QHW casi exacto (α_std 1.11° vs 1.12°, NIS 1.50 vs 1.52); la
  box algo más apretada (α_std 0.60°) por ser sustrato bare-metal.

**Lo que quedó DESCARTADO** (era la hipótesis previa equivocada): que el C-Script PLANTA de la box
tuviera la inercia del péndulo mal parametrizada (~1/4) dando 3.52 Hz / 1.94× off. La física de la box
siempre fue correcta: `M22 = Jp_cm + lp²·mp = 1.324e-4`, estados continuos integrados a 0.5 ms. NO hay
que regenerar el C-Script PLANTA por "inercia".

**Precaución de duplicados (lección del proceso):** el `2× off` desaparece con `seq×2 ms`, pero E2 tuvo
además dos trampas de archivo que sí importan y se verifican **por contenido**, no por nombre/fecha:
(1) el `RATIO` de la excitación — con `RATIO=2` la excitación se estira 2× (arranca en 2.0 s, mal); la
buena tiene `RATIO=1` (arranca en 1.0 s); (2) una corrida intermedia de E2 quedó con la PLANTA de
inercia vieja (α se dispara a [3, 317]°, respondiendo ~30× de más al Vm). La corrida válida de E2 es la
que tiene onset 1.0 s **y** α ∈ ~[113, 237]° (coincide con QSM/real). Ver `memo_correccion_2ms_RTBOX.md`.

Gráficas del diagnóstico (regeneradas): `E1_rtbox_senales.png`, `E2_rtbox_senales.png`,
`E3_rtbox_senales.png`, `E3_rtbox_alpha.png`, `rtbox_barrido_{openloop,closedloop}.png`.

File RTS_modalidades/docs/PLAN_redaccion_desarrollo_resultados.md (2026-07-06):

# Plan de redacción — última sección de Desarrollo e "Resultados"

Guion para cerrar el LaTeX. Insumos ya listos en `TESIS_FINALES/RTS_modalidades/` (figuras, tablas,
docs por modalidad, hallazgos). Convención de figuras del proyecto: 1 plot → sin título (caption en
LaTeX); varios subplots → cada uno con su título, sin título general; ejes en grados.

---

## A. DESARROLLO — "Implementación de las cuatro modalidades" (última sección)

Objetivo: describir el **montaje** de cada modalidad (no los datos; los datos van a Resultados).
Corrige la sección actual (que decía "3 modalidades", "RT Box pendiente" y "QUARC usa timer de hardware").

1. **Encuadre (½ pág).** Las 4 modalidades (SIM, QSM, QHW, RTB) del mismo gemelo M1 contra la planta real
   M0, en 3 experimentos (E1 caída libre, E2 respuesta forzada, E3 lazo cerrado swing-up+balance+EKF).
   Molde común: Ts=2 ms, misma excitación (E2), misma CI, convención α=0 arriba. Tabla resumen
   (modalidad | sustrato | planta | RTF | naturaleza) — de `DOCUMENTACION_GENERAL_RTS_unificada.md §1`.

2. **SIM (sim normal).** Simulink Normal, ode4 2 ms, `furuta_planta_analitica` (RK4 nsub=4). Solo RTF por
   `tic/toc`. Breve (`doc_SIM.md`). Captura del esquemático `E*_SIM`.

3. **QSM (QUARC-modelo).** Kernel QUARC, M1 en bloques (`furuta_planta_analitica` + `ekf_step`), lazo roto
   con `Unit Delay z⁻¹`. Captura de RTS (`Computation Time`, `System Time`, `Counter`). **Hallazgo del
   piso de 1 ms** del timer de software de Windows y el **fast system timer** (experimental, multinúcleo)
   — corregir aquí el error de "timer de hardware". Esquemáticos `E*_QSM_SIMULINK.png`. Extenso
   (`doc_QSM.md`).

4. **QHW (QUARC-real, M0).** Igual que QSM pero I/O físico por HIL API; `−1` de *For +ve CCW*; en E1 se
   suelta a mano (recorte). Referencia de fidelidad. Esquemáticos `E*_QHW_SIMULINK.png`. Breve
   (`doc_QHW.md`).

5. **RTB (RT Box).** C-Scripts PLANTA/CONTROL/EXCITACION, Euler 0.5 ms (sin ode4), log a 2 ms
   (`subTaskPeriod=4`). Captura de RTS por web/API (`rtbox_watch.py`, Application Log). Esquemáticos
   `E*_PLECS.png`. Extenso (`doc_RTB.md`).

6. **Diferencias de sustrato (½–1 pág, tabla).** Solver (Euler box vs ode4/RK4 QUARC), timer
   (hardware timebase box/HIL vs software Windows), captura de TET/overruns (API box vs bloques QUARC),
   RTF. Tabla de `COMPARACION_4_modalidades.md §2`. Aquí se justifica por qué "el mismo modelo" no da
   bit-idéntico entre sustratos (integrador).

Figuras de Desarrollo: esquemáticos (`*_SIMULINK.png`, `*_PLECS.png`) y scopes (`*_scope_*`) de cada
carpeta — ilustran el montaje, no los resultados.

---

## B. RESULTADOS — comparación de las cuatro modalidades

### B.1 Fidelidad (gemelo vs real M0)
- **E1 (caída libre):** tabla `f_n`/ζ de las 4 (RTB 1.76 / QSM 1.72 / SIM 1.72 / QHW 1.82 Hz).
  Figura `comp_E1_alpha_4mod.png` (4-way) y `comp_E1_alpha_vsreal.png` (subplots vs real).
- **E2 (respuesta forzada):** tabla de rangos θ/α + Vm; opcional RMSE θ/α alineado por τ*.
  Figuras `comp_E2_alpha_theta_4mod.png`, `comp_E2_{alpha,theta}_vsreal.png`.
- **E3 (lazo cerrado):** tabla de índices (t_catch, balance %, α̂_std, θ_std, **NIS en tabla, no figura**).
  Figuras `comp_E3_{alpha,theta,Vm,alphadot,E}_4mod.png` y `comp_E3_{alpha,theta}_vsreal.png`.
  → aquí entra el **hallazgo del vaivén extra** (§B.4).

  Tabla E3 (valores actuales):
  | mod | t_catch | balance % | α̂_std° | θ_std° | NIS |
  |---|---|---|---|---|---|
  | RTB | 2.72 | 91.6–93.8 | 0.51–0.60 | 0.66–0.69 | 1.10 |
  | QSM | 3.13 | 79.1 | 1.11 | 3.10 | 1.50 |
  | SIM | 3.13 | 79.1 | 1.11 | 3.10 | 1.50 |
  | QHW | 2.65 | 82.3 | 1.12 | 3.14 | 1.52 |

### B.2 RTS (impacto del tiempo real)
- Tabla RTF/TET/umbral-overrun/jitter de las 4 (`COMPARACION_4_modalidades.md §2`).
- Barridos: box abierto/cerrado (`rtbox_barrido_*`), QSM fast timer (`E1_qsm_barrido_fasttimer.png`,
  `E3_qsm_barrido_abierto_vs_cerrado.png`; tabla de `barridos_qsm.mat`).
- Hallazgos: **RTF≈2 de la box** (no sostuvo 1:1), **piso de 1 ms de QUARC** + fast timer, **jitter por
  timebase** (box sub-µs ≪ QHW HIL 36–70 µs ≪ QSM software 320 µs).
- Trade-off: *compute-bound* (box, determinista) vs *timer/jitter-bound* (QUARC, throughput).

### B.3 Comparación cruzada vs M0
- Overlays α/θ de las 4 vs el real (figuras B.1). Lectura: sustrato NO cambia la fidelidad
  (RTB≈QSM≈SIM), brecha M1↔M0 ~5%; QSM≈QHW casi exacto en balance.

### B.4 Hallazgo del vaivén extra (subsección propia) — `hallazgo_swingup_integrador.md`
- El analítico (RK4) hace 8 vaivenes vs 7 del RTB/3D/real. **No es defecto de fidelidad** (evidencia:
  fidelidad abierta, planta≡EKF 1.7e-13, 3D≈real 2.66 vs 2.65 s). **Es el integrador + umbral** (RK4→8,
  Euler→7; ke 50→52 pasa a 7). Figuras `hallazgo_swingup_{rk4_vs_euler,barrido_ke,ke52_vs_real}.png`,
  `respaldo_3D_vs_real_lazocerrado.png`, `diag_catch_qsm.png`. Es un resultado de RTS/numérico.

### B.5 Parte cualitativa (recordatorio) 
- Modelamiento α/θ y comparación en paralelo: (a) lazo cerrado real + EKF + control, (b) mismo esquema con
  modelo 3D. En Desarrollo fue cuantitativo; aquí cualitativo (`respaldo_3D_vs_real_lazocerrado.png` y
  figuras del gemelo en `TESIS_FINALES/`). Causas físicas de la brecha M1↔M0: cable-jack/histéresis,
  conector USB-C (artefacto del banco), stiction — parámetros no modelados a detalle.

---

## C. Orden sugerido de escritura
1. Desarrollo A (montajes) — reusar `doc_RTB/QSM/QHW/SIM.md`.
2. Resultados B.1 fidelidad → B.2 RTS → B.3 cruzada.
3. B.4 hallazgo del swing-up (cierra la duda del vaivén).
4. B.5 cualitativo + conclusiones parciales.

Pendiente opcional antes de redactar: RMSE θ/α por τ* en E2 (cuantitativo punto-a-punto); decidir ke=50
(documentar) vs ke=52 (re-correr SIM+QSM).

---

## D. Añadidos cuantitativos y de encuadre (iteración de cierre)

Estos insumos se integran en las secciones ya listadas; no las reemplazan.

- **RMSE θ/α cuantitativo** (`metricas_cuantitativas.md`, `metricas_cuantitativas.mat`, script
  `metricas_cuantitativas.m`). Entra en B.1 (fidelidad) como respaldo punto-a-punto:
  - E2 por **amplitud** (la coherencia temporal cae a ~0.45 por deriva de fase del barrido):
    α del analítico RK4 (QSM/SIM) 3.0 % vs real; α del Euler (RTB) 20.2 % — el Euler infla la
    amplitud, mismo efecto que decide el vaivén.
  - E3 **balance** (post-captura): RMSE α < 2° en todas; equivalente entre ke=50 y ke=52.
  - **3D**: t_captura 2.656 vs 2.650 s; α balance RMS 1.26° vs 1.20°.
- **Figuras ke=52** (`comp_E3_*_ke52*.png`): el analítico con 7 vaivenes que iguala al real, junto
  a las de ke=50 (hallazgo). SIM≡QSM verificado bit a bit. Se presentan en pareja en B.1/B.4.
- **Cuantitativo del 3D** (`metricas_cuantitativas.md §3D`): da números a lo que en B.5 era
  cualitativo (t_captura, RMSE de balance, α balance RMS).
- **Segundo hallazgo — dificultad del gemelo de Furuta** (`hallazgo_dificultad_gemelo_furuta.md`):
  nueva subsección **B.6** (o encuadre de conclusiones parciales). Reencuadra el vaivén extra como
  un caso concreto de una propiedad general: la fidelidad de un sistema subactuado e inestable no
  se captura solo con métricas de lazo abierto, y el sustrato/integrador no es neutro. Justifica el
  estudio multi-sustrato.
- **Orientación de figuras corregida**: α por signo del mayor vaivén del swing-up; θ/Vm por
  correlación en continuo. Ninguna curva queda invertida respecto al real (antes QSM/SIM sí).

### Tabla E3 — filas ke=52 añadidas (no sustituyen a las de ke=50)

| mod | t_catch [s] | balance % | RMSE α bal [°] | RMSE θ bal [°] |
|---|---|---|---|---|
| QSM ke=52 | 2.754 | 81.6 | 1.71 | 6.15 |
| SIM ke=52 | 2.754 | 81.6 | 1.71 | 6.15 |
| real (QHW) | 2.654 | 82.3 | — | — |

Nota: θ del gemelo analítico dispersa algo más que el real en el balance (std ~5–7° vs ~1.6° del
real/RTB), coherente con un brazo menos amortiguado en el modelo (stiction/fricción del banco no
modelada a detalle). El RTB, con Euler, replica mejor la dispersión de θ del real.

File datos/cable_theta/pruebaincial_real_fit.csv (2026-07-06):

t | theta | alpha | Vm
0.000000 | -0.000000 | 0.000000 | -1.000000
0.002000 | -0.000000 | 0.000000 | -1.000000
0.004000 | -0.000000 | 0.000000 | -1.000000
0.006000 | -0.000000 | 0.003068 | -1.000000
0.008000 | -0.003068 | 0.003068 | -1.000000
0.010000 | -0.003068 | 0.003068 | -1.000000
0.012000 | -0.003068 | 0.003068 | -1.000000
0.014000 | -0.003068 | 0.003068 | -1.000000
0.016000 | -0.006136 | 0.006136 | -1.000000
0.018000 | -0.006136 | 0.006136 | -1.000000
0.020000 | -0.006136 | 0.006136 | -1.000000
0.022000 | -0.009204 | 0.009204 | -1.000000
0.024000 | -0.009204 | 0.009204 | -1.000000
0.026000 | -0.012272 | 0.012272 | -1.000000
0.028000 | -0.012272 | 0.015340 | -1.000000
0.030000 | -0.015340 | 0.015340 | -1.000000
0.032000 | -0.018408 | 0.018408 | -1.000000
0.034000 | -0.018408 | 0.021476 | -1.000000
0.036000 | -0.021476 | 0.021476 | -1.000000
0.038000 | -0.024544 | 0.024544 | -1.000000
0.040000 | -0.027612 | 0.027612 | -1.000000
0.042000 | -0.030680 | 0.030680 | -1.000000
0.044000 | -0.030680 | 0.033748 | -1.000000
0.046000 | -0.033748 | 0.036816 | -1.000000
0.048000 | -0.036816 | 0.039884 | -1.000000
0.050000 | -0.039884 | 0.042951 | -1.000000
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

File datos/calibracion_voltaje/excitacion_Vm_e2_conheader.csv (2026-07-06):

t | Vm
0 | 0
0.002 | 0
0.004 | 0
0.006 | 0
0.008 | 0
0.01 | 0
0.012 | 0
0.014 | 0
0.016 | 0
0.018 | 0
0.02 | 0
0.022 | 0
0.024 | 0
0.026 | 0
0.028 | 0
0.03 | 0
0.032 | 0
0.034 | 0
0.036 | 0
0.038 | 0
0.04 | 0
0.042 | 0
0.044 | 0
0.046 | 0
0.048 | 0
0.05 | 0
0.052 | 0
0.054 | 0
0.056 | 0
0.058 | 0
0.06 | 0
0.062 | 0
0.064 | 0
0.066 | 0
0.068 | 0
0.07 | 0
0.072 | 0
0.074 | 0
0.076 | 0
0.078 | 0
0.08 | 0
0.082 | 0
0.084 | 0
0.086 | 0
0.088 | 0
0.09 | 0
0.092 | 0
0.094 | 0
0.096 | 0
0.098 | 0
0.1 | 0
0.102 | 0
0.104 | 0
0.106 | 0
0.108 | 0
0.11 | 0
0.112 | 0
0.114 | 0
0.116 | 0
0.118 | 0
0.12 | 0
0.122 | 0
0.124 | 0
0.126 | 0
0.128 | 0
0.13 | 0
0.132 | 0
0.134 | 0
0.136 | 0
0.138 | 0
0.14 | 0
0.142 | 0
0.144 | 0
0.146 | 0
0.148 | 0
0.15 | 0
0.152 | 0
0.154 | 0
0.156 | 0
0.158 | 0
0.16 | 0
0.162 | 0
0.164 | 0
0.166 | 0
0.168 | 0
0.17 | 0
0.172 | 0
0.174 | 0
0.176 | 0
0.178 | 0
0.18 | 0
0.182 | 0
0.184 | 0
0.186 | 0
0.188 | 0
0.19 | 0
0.192 | 0
0.194 | 0
0.196 | 0
0.198 | 0
0.2 | 0
0.202 | 0
0.204 | 0
0.206 | 0
0.208 | 0
0.21 | 0
0.212 | 0
0.214 | 0
0.216 | 0
0.218 | 0
0.22 | 0
0.222 | 0
0.224 | 0
0.226 | 0
0.228 | 0
0.23 | 0
0.232 | 0
0.234 | 0
0.236 | 0
0.238 | 0
0.24 | 0
0.242 | 0
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

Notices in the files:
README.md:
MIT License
